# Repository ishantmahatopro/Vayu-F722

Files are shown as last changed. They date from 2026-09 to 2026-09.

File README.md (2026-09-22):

<h1 align="center">
  <br>
  Vayu F7
  <br>
</h1>

<h4 align="center">
A production-grade STM32F722 FPV flight controller built in KiCad, designed for
5-inch and 7-inch builds and documented the same way as a serious hardware
project should be.
</h4>

<div align="center">






</div>

<p align="center">
  <a href="#what-it-is">What it is</a> •
  <a href="#specifications">Specifications</a> •
  <a href="#hardware-overview">Hardware overview</a> •
  <a href="#pinout">Pinout</a> •
  <a href="#flight-controller-firmware">Firmware</a> •
  <a href="#building-one">Building one</a> •
  <a href="#license">License</a>
</p>

---

## What it is

*Vayu* (वायु) is the Sanskrit word for wind.

This is a 42 × 42 mm, four-layer FPV flight controller built around the
STM32F722 for 5-inch and 7-inch quads doing cinematic, telemetry, and general
performance work. It is designed to sit in the same class as well-known F722
boards while adding a cleaner power layout, a proper barometer, and a 10 V rail
sized for an HD VTX or analogue system.

The board is fully designed in KiCad.

## Specifications

| | |
|---|---|
| **MCU** | STM32F722RET6, Cortex-M7 @ 216 MHz, 512 KB flash, 256 KB RAM |
| **Gyro / accel** | ICM-42688-P on SPI1 |
| **Barometer** | BMP388 on I²C1 |
| **Blackbox** | W25Q128JVSIQ — 16 MB SPI NOR on its own bus |
| **OSD** | AT7456E analogue OSD, fitted |
| **Input** | 3S–6S (11.1–25.2 V), TVS clamp on the battery rail |
| **5 V BEC** | AP64350 synchronous buck, 5.00 V, 2 A |
| **10 V BEC** | AP64350 synchronous buck, 10.06 V, switchable for VTX rail |
| **3.3 V** | TLV62569 buck + LP5907-3.3 LDO for analogue rail |
| **Motor outputs** | 4 outputs with timer-backed DShot-capable design |
| **UARTs** | 6 total, with pads and connector-backed serial ports |
| **I²C** | 1, on the GPS connector |
| **Board** | 42 × 42 mm, 30.5 × 30.5 mm M3 mounting, 4 layers, 1.6 mm |
| **Stack-up** | F.Cu signal / **In1.Cu solid ground plane** / In2.Cu signal + ground pour / B.Cu signal |
| **Connectors** | ESC, GPS-I²C, RX, camera, VTX, USB-C |

### Power budget

| Rail | Source | Typical role |
|---|---|---|
| +10V | AP64350 buck | HD VTX / high-power video rail |
| +5V | AP64350 buck | main logic and peripheral rail |
| +3V3 | TLV62569 + LP5907 | MCU, IMU, barometer, logic |
| VBAT | input connector | raw battery feed for the switching rails |
| USB_VBUS | USB-C | debug / boot / low-power use |

## Pinout

The connector map is documented in the repo and kept together with the hardware
notes. The board includes the usual FPV stack connectors for:

| Connector | Purpose | Notes |
|---|---|---|
| ESC | Motor outputs and battery feed | 8-pin JST-SH style connector |
| GPS / I²C | GPS and barometer / compass bus | I²C and UART combination |
| HD VTX | Video and telemetry port | For HD VTX systems |
| RX | Serial receiver connection | Standard FPV receiver port |
| Camera | Camera connection | Analog / camera feed path |
| USB-C | DFU / flashing / debug | Board programming and serial access |

## Flight controller firmware

Because this project is a custom hardware layout, firmware is normally built from
upstream Betaflight or iNav sources rather than from a pre-generated target in a
factory build. The repository includes the custom target scaffold for both
firmware ecosystems so the board can be adapted to the normal upstream build
process.

### Betaflight

This repository now includes the custom Betaflight target definition at
[firmware/source/betaflight/config.h](firmware/source/betaflight/config.h).

1. Clone the upstream Betaflight repository.
2. Install the required GCC / toolchain dependencies.
3. Run `make configs` in the Betaflight tree.
4. Create a custom target directory, for example `src/config/configs/VAYUF7/`.
5. Copy [firmware/source/betaflight/config.h](firmware/source/betaflight/config.h)
   into that target directory.
6. Build the target with `make VAYUF7`.
7. Flash the resulting `.hex` via USB DFU or SWD.

The board mapping used in the target is aligned to the actual hardware:
- STM32F722RET6
- ICM-42688-P on SPI1
- BMP388 on I2C1
- AT7456E on SPI2
- W25Q128 on SPI3
- 4 motor outputs on timer-backed pins

### iNav

This repository also includes the custom iNav target files in
[firmware/source/inav/CMakeLists.txt](firmware/source/inav/CMakeLists.txt),
[firmware/source/inav/target.c](firmware/source/inav/target.c), and
[firmware/source/inav/target.h](firmware/source/inav/target.h).

1. Clone the upstream iNav repository.
2. Check out a supported stable release.
3. Create a target directory, for example `src/main/target/VAYUF7/`.
4. Copy the files from [firmware/source/inav](firmware/source/inav) into that
   target folder.
5. Configure the project with `cmake ..` inside the build directory.
6. Build the target with the normal iNav build command.
7. Flash the resulting `.hex` through USB or SWD.

> The hardware design is intentionally kept independent of any vendor-specific
> firmware stack so the board can be supported by upstream projects when the
> target is created.

## Building one

Current state — revision **R6**:

| Check | Result |
|---|---|
| KiCad DRC | **0 errors**, 0 unconnected pads (1 cosmetic silk warning) |
| KiCad ERC | **0 errors, 0 warnings** |
| Schematic ↔ board netlist | match, 483 pins / 105 nets, 0 mismatches |
| Electrical stress | all pass; worst capacitor 52.8 %, worst resistor 57.6 % of rating |
| HSE gain margin | 2.4× at C0 = 3 pF |
| Minimum via annular ring | 0.125 mm, every via ≥ 0.45 mm diameter |
| Datasheet cross-check | no mismatch found in the main design references |

The project is intentionally documented as a real engineering board, not just a
rendered concept. The repository includes a project status file, revision notes,
and hardware validation data so the design can be tracked from concept through
manufacturing readiness.

The main project constraints are documented openly:

- the board is input-limited on the battery connector at the real system level
- the 10 V rail is sized for VTX use but still obeys the regulator and layout
  limits
- all critical traces, regulator loops, and crystal areas are checked as part of
  the design review rather than left implicit

## Bill of material

The design uses practical, mainstream FPV parts that are suitable for a
production-style board and are chosen with sourcing and assembly in mind. The key
parts in the current hardware are:

| Category | Item | Notes |
|---|---|---|
| MCU | STM32F722RET6 | 32-bit F7 core, 216 MHz |
| IMU | ICM-42688-P | SPI-based gyro / accel |
| Barometer | BMP388 | I²C pressure sensor |
| Flash | W25Q128JVSIQ | 16 MB SPI NOR blackbox memory |
| OSD | AT7456E | Analog video overlay device |
| Regulators | AP64350 + LP5907 / TLV62569 | 5 V, 10 V, 3.3 V generation |
| Connectors | JST-SH / USB-C | Standard FPV and service interfaces |
| Board | 4-layer PCB | 42 × 42 mm, 30.5 × 30.5 mm mounting |

The repository is organized around the actual board design, not around a generic
marketing sheet. The hardware files, status records, and revision notes are the
source of truth for assembly and manufacturing decisions.

## BOM

The table below is the assembly BOM generated from the production files. Prices
are indicative USD unit prices from the currently displayed LCSC quantity tier
for the listed minimum order, checked on 2026-09-22. They exclude PCB
fabrication, assembly, shipping, tax, and tooling. `quote` means the public
product page did not expose a current price and should be checked in the JLCPCB
order quote.

| SL NO | LCSC NO | COMPONENT | PRICE IN USD |
|---:|---|---|---:|
| 1 | C29823 | C1, C2 - 4.7uF/50V, qty 2 | 0.0853 |
| 2 | C12891 | C10, C14, C15, C17, C8, C9 - 22uF/25V, qty 6 | 0.0904 |
| 3 | C1525 | C11, C5 - 100nF/16V, qty 2 | 0.0023 |
| 4 | C1531 | C12, C60 - 2.2nF, qty 2 | 0.0014 |
| 5 | C106203 | C13 - 22pF, qty 1 | 0.0023 |
| 6 | C3039694 | C16, C34 - 10uF/16V, qty 2 | 0.0699 |
| 7 | C307331 | C18, C21, C23, C24, C25, C26, C27, C30, C33, C35, C37, C38, C39, C40, C41, C42, C43, C46, C50, C51, C56, C58 - 100nF/50V, qty 22 | 0.0046 |
| 8 | C5199872 | C19, C20, C22, C49 - 1uF/50V, qty 4 | 0.0107 |
| 9 | C2885646 | C28, C29 - 4.7uF/16V, qty 2 | 0.0236 |
| 10 | C437557 | C3, C52, C53, C54, C55 - 4.7uF/50V, qty 5 | 0.1152 |
| 11 | C107004 | C31, C32 - 15pF, qty 2 | 0.0013 |
| 12 | C415535 | C36 - 2.2uF/16V, qty 1 | 0.0412 |
| 13 | C14663 | C4 - 100nF/50V, qty 1 | 0.0052 |
| 14 | C45783 | C47, C48 - 22uF/16V, qty 2 | 0.1037 |
| 15 | C189470 | C59 - 6.8pF, qty 1 | 0.0016 |
| 16 | C107024 | C6 - 1.8nF, qty 1 | 0.0021 |
| 17 | C107002 | C7 - 27pF, qty 1 | 0.0015 |
| 18 | C908777 | D1 - SMAJ33A, qty 1 | 0.0167 |
| 19 | C64885 | D4 - B5819W, qty 1 | 0.0091 |
| 20 | C2286 | D5 - RED 3V3, qty 1 | 0.0035 |
| 21 | C965804 | D6 - GREEN 5V, qty 1 | 0.0031 |
| 22 | C965802 | D7 - YELLOW VBAT, qty 1 | 0.0038 |
| 23 | C965807 | D8 - BLUE STATUS, qty 1 | 0.0027 |
| 24 | C1017 | FB1 - 600R@100MHz 2A, qty 1 | quote |
| 25 | C160407 | J1 - ESC 8P, qty 1 | 0.1840 |
| 26 | C53055322 | J2 - HD VTX 6P, qty 1 | 0.0349 |
| 27 | C160404 | J3 - RX 4P, qty 1 | 0.1245 |
| 28 | C53055322 | J4 - GPS/I2C 6P, qty 1 | 0.0349 |
| 29 | C160404 | J5 - CAM 4P, qty 1 | 0.1245 |
| 30 | C160404 | J6 - VTX 4P, qty 1 | 0.1245 |
| 31 | C165948 | J8 - USB-C 16P, qty 1 | 0.0971 |
| 32 | C167221 | L1 - 6.8uH FXL0630-6R8-M, qty 1 | 0.0827 |
| 33 | C189932 | L2 - 10uH SRP5030T-100M, qty 1 | 0.6640 |
| 34 | C50543 | L3 - 2.2uH SWPA4018S2R2MT, qty 1 | quote |
| 35 | C8545 | Q1 - 2N7002, qty 1 | 0.0106 |
| 36 | C20917 | Q2 - AO3400A, qty 1 | 0.0482 |
| 37 | C159047 | R1, R7 - 294k, qty 2 | 0.0004 |
| 38 | C25748 | R10 - 118k, qty 1 | 0.0013 |
| 39 | C5153958 | R11, R5 - 10.2k, qty 2 | 0.0010 |
| 40 | C2998091 | R12 - 31.6k, qty 1 | 0.0014 |
| 41 | C25744 | R13, R14, R20, R28, R34, R35, R36, R37, R38, R50 - 10k, qty 10 | 0.0017 |
| 42 | C25905 | R16, R17 - 5.1k, qty 2 | 0.0012 |
| 43 | C25879 | R18, R19, R25, R26, R39 - 2.2k, qty 5 | 0.0026 |
| 44 | C2960799 | R2, R8 - 57.6k, qty 2 | 0.0012 |
| 45 | C2909384 | R21, R22 - 75R, qty 2 | 0.0013 |
| 46 | C25804 | R23 - 10k, qty 1 | 0.0012 |
| 47 | C11702 | R24, R30, R33, R40, R41 - 1k, qty 5 | 0.0012 |
| 48 | C25741 | R27, R49 - 100k, qty 2 | 0.0013 |
| 49 | C22369194 | R29 - 100R, qty 1 | quote |
| 50 | C2909325 | R3 - 180k, qty 1 | 0.0012 |
| 51 | C25867 | R31 - 1.5k, qty 1 | 0.0013 |
| 52 | C22809 | R32 - 15k, qty 1 | 0.0014 |
| 53 | C53398 | R4 - 53.6k, qty 1 | 0.0008 |
| 54 | C2906868 | R42, R43, R44, R45, R47 - 33R, qty 5 | 0.0012 |
| 55 | C3013172 | R48 - 453k, qty 1 | 0.0013 |
| 56 | C2998160 | R6 - 25.5k, qty 1 | 0.0013 |
| 57 | C2909311 | R9 - 110k, qty 1 | 0.0009 |
| 58 | C231329 | SW1 - BOOT, qty 1 | 0.1025 |
| 59 | C2071691 | U1, U2 - AP64350SP-13, qty 2 | 1.1554 |
| 60 | C82351 | U10 - AT7456E, qty 1 | 1.7093 |
| 61 | C141836 | U3 - TLV62569DBVR, qty 1 | 0.0441 |
| 62 | C80670 | U4 - LP5907MFX-3.3, qty 1 | 0.1260 |
| 63 | C118207 | U5 - STM32F722RET6, qty 1 | 6.9322 |
| 64 | C2687116 | U6 - USBLC6-2SC6, qty 1 | 0.0221 |
| 65 | C1850418 | U7 - ICM-42688-P, qty 1 | 15.6022 |
| 66 | C779278 | U8 - BMP388, qty 1 | 3.6120 |
| 67 | C97521 | U9 - W25Q128JVSIQ, qty 1 | 1.6422 |
| 68 | C2682775 | X1 - 8MHz X32258MOB4SI 12pF, qty 1 | 0.0937 |
| 69 | C9008 | X2 - 27MHz X322527MSB4SI, qty 1 | 0.0489 |
| 70 | | PCB, qty 5 | 27.54 |
| 71 | | PCBA, qty 2 | 130

## Board renders

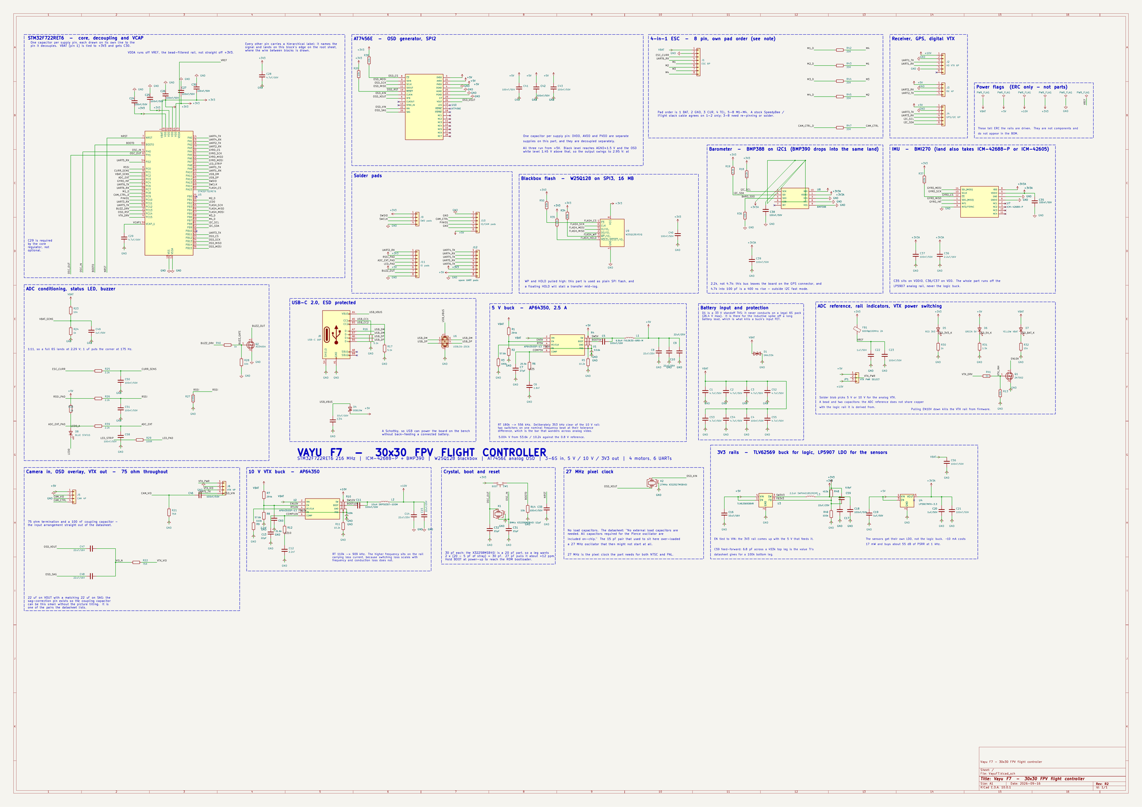
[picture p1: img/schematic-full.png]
schematic


### - If its hard to zoom please check out /img folder to see each part of the schematic much more clearly, I tried using .pdf to .img but unfortunately u can't see the text on zooming in... hence I have taken SS of each component.

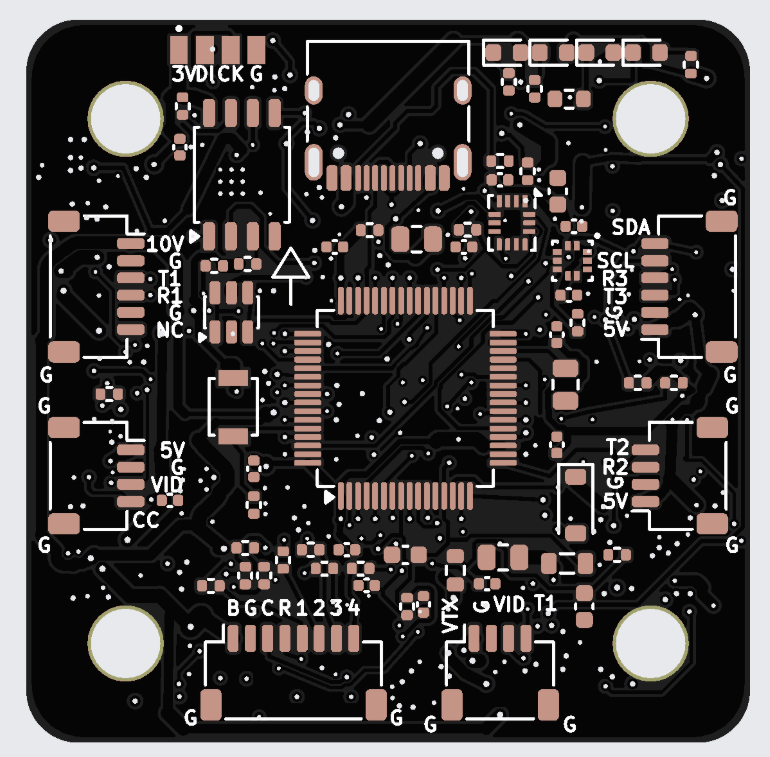
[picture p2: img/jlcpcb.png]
JLCPCB


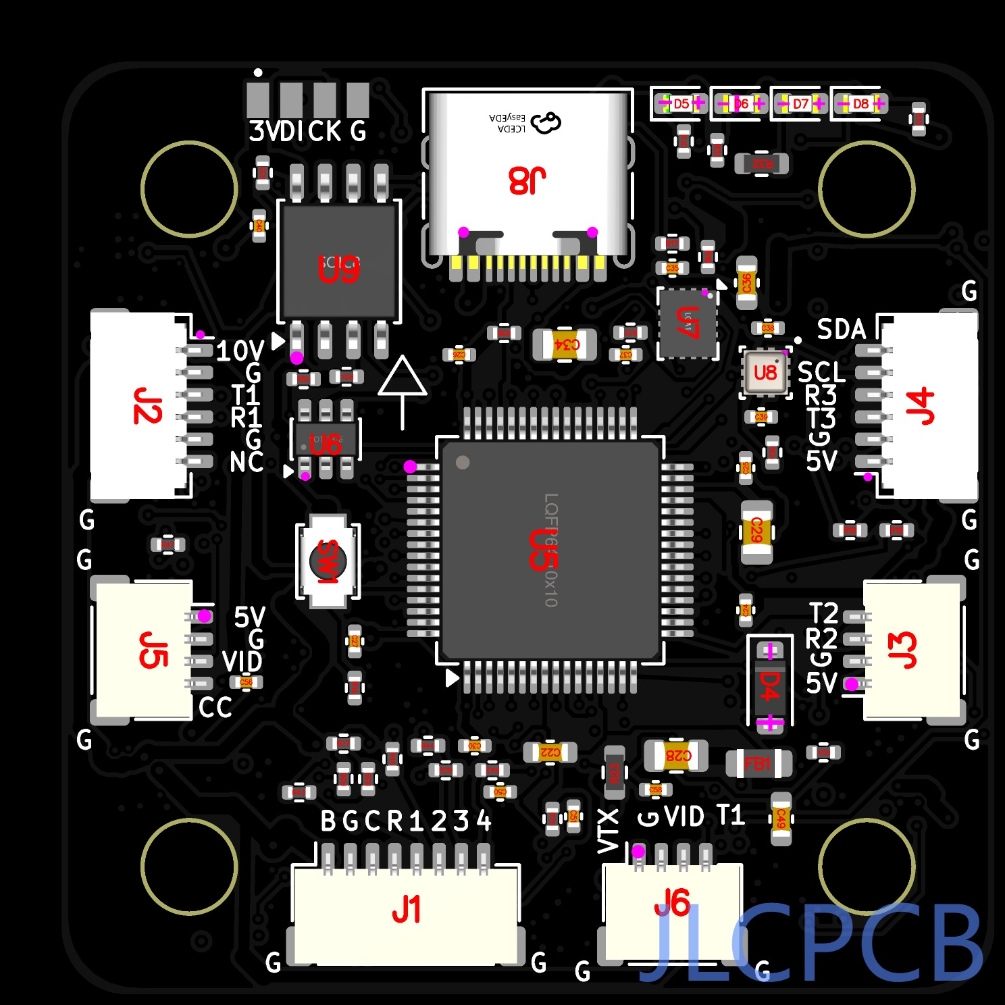
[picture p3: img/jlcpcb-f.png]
Front


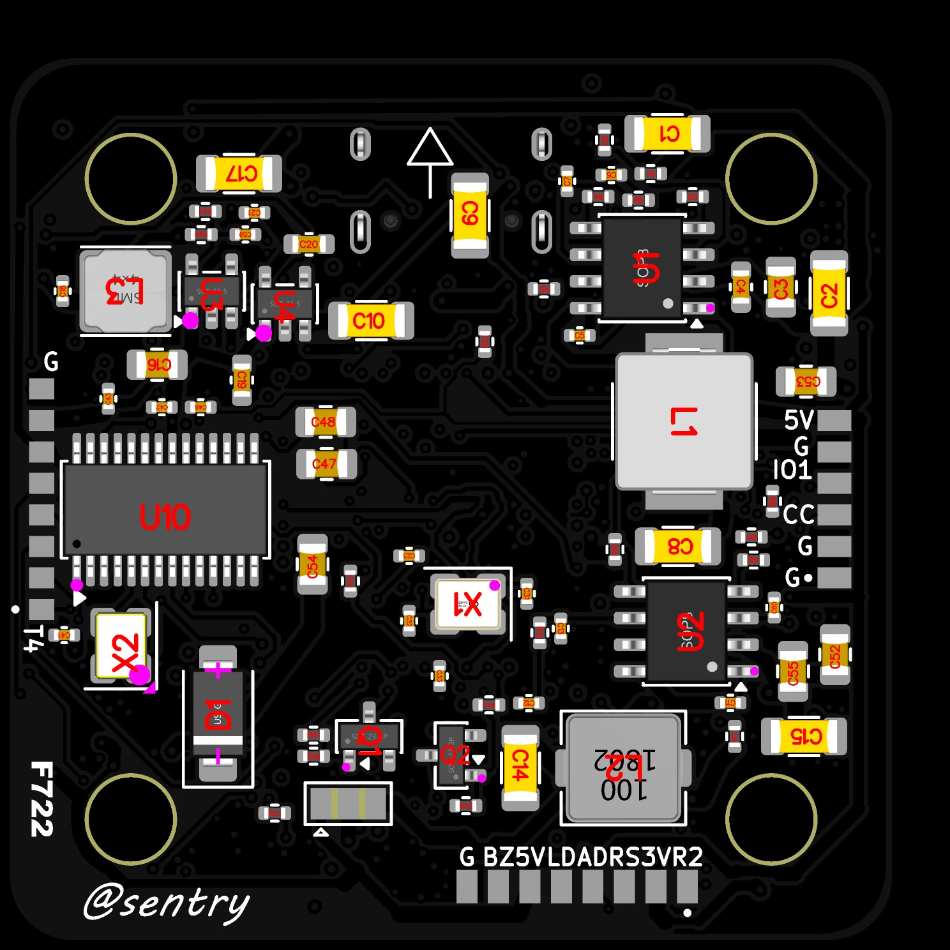
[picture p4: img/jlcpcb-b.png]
Back


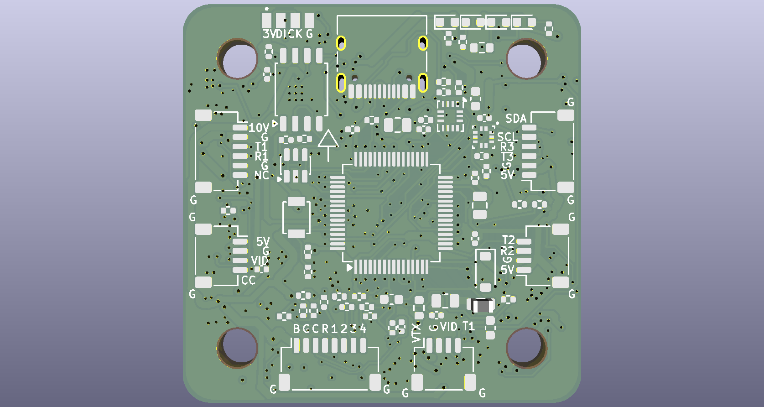
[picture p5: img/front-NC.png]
Vayu F7 front render without components


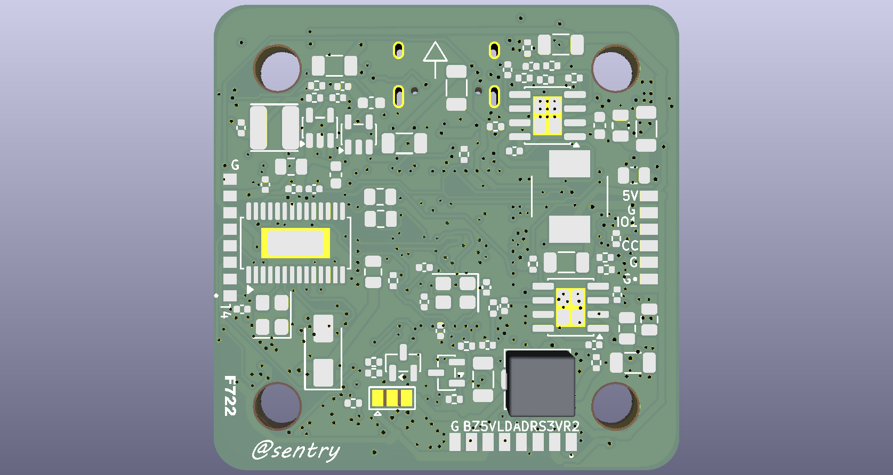
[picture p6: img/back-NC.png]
Vayu F7 back render without components


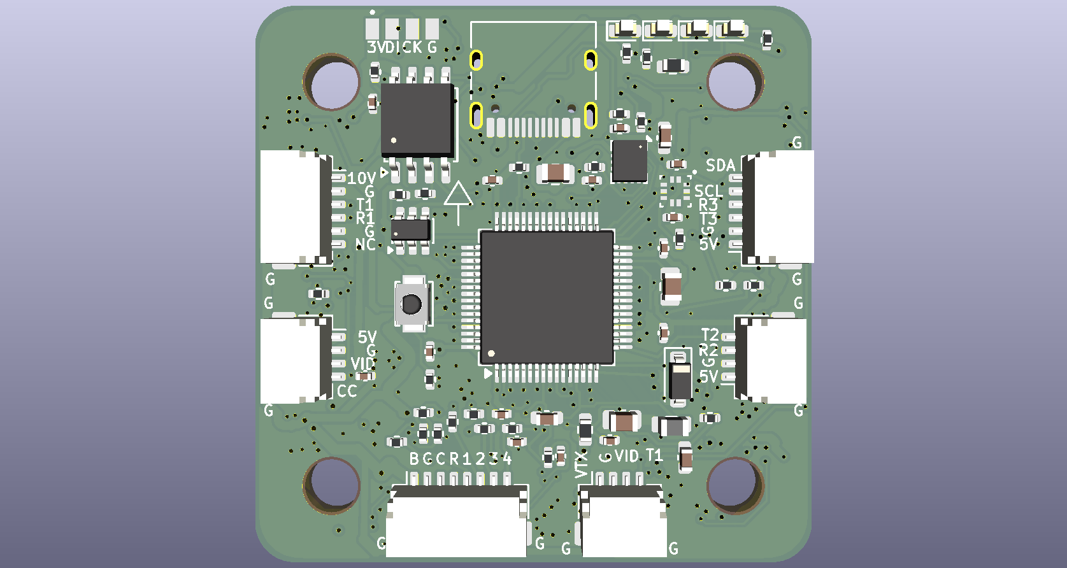
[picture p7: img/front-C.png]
Vayu F7 front render with components


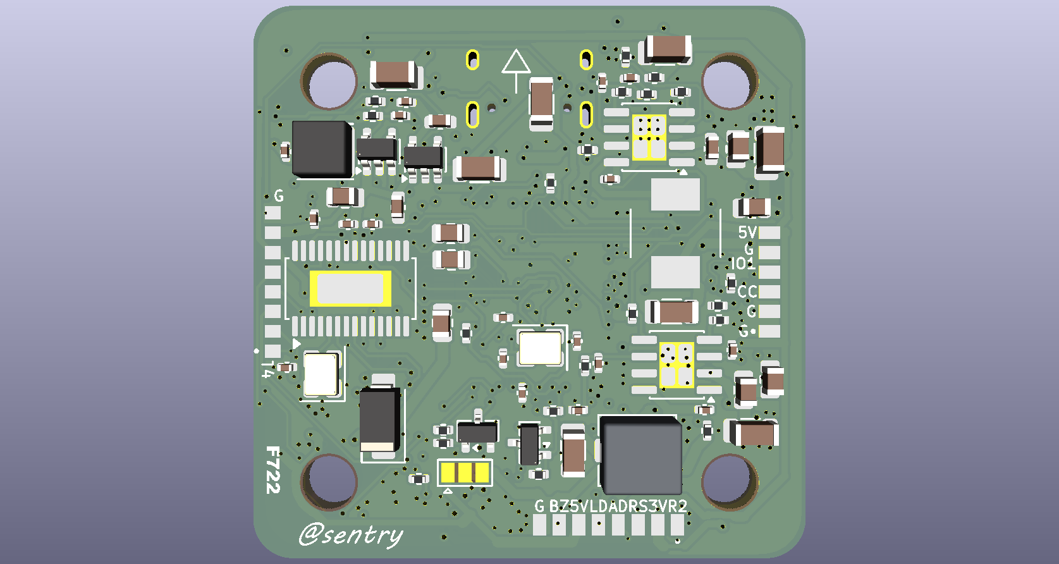
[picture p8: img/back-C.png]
Vayu F7 back render with components


## Credits

- [KiCad](https://www.kicad.org/)
- [INAV](https://github.com/iNavFlight/inav)
- [Betaflight](https://github.com/betaflight/betaflight)
- [JLCPCB](https://jlcpcb.com/) and [LCSC](https://www.lcsc.com/)
- [Hack Club Blueprint](https://blueprint.hackclub.com/)
- The original open hardware and design process references that inspired this
  board-level documentation approach

## AI usage
This project was designed and built with the help of AI ChatGPT 5.6 precisely... AI was used to extract key important design rules for different componets pulling it off their 200pages chinglish docs ( chinese + english ). Help in creating a netlist, chosing components and drawing the schematic.
Also AI was used in writing the firmware...

> As mentioned in the resource docs, no AI was used to write slopped Journal or REAMDE.

## License

MIT

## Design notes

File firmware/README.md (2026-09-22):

# Vayu F7 firmware targets

This directory contains the custom upstream target scaffolding for the Vayu F7 hardware.

The board is designed around an STM32F722RET6, a 3-axis gyro / accel sensor, a BMP388 barometer, a W25Q128 blackbox flash chip, and a standard FPV serial / video stack. The target files here are intentionally kept generic so they can be dropped into the upstream build trees for Betaflight and iNav without depending on a vendor-specific firmware package.

## Included targets

- `source/betaflight/config.h` — Betaflight target definition for a custom `VAYUF7` target.
- `source/inav/CMakeLists.txt` — iNav target registration
- `source/inav/target.c` — timer and output mapping
- `source/inav/target.h` — board identifier and peripheral map

## Hardware assumptions

The scaffold is aligned to the live Vayu F7 schematic and current design notes:

- MCU: STM32F722RET6
- Gyro / accel: ICM-42688-P on SPI1
- Barometer: BMP388 on I2C1
- OSD: AT7456E on SPI2
- Blackbox flash: W25Q128 on SPI3
- Motor outputs: 4 timer-backed outputs on TIM1/TIM2-style mappings
- UARTs: standard serial ports for RX / GPS / telemetry / VTX / debug

## Building upstream targets

### Betaflight

1. Clone the upstream Betaflight repository.
2. Install the required toolchain.
3. Copy `source/betaflight/config.h` into the relevant custom target directory in the Betaflight tree.
4. Build with the normal target generation flow for the board.
5. Flash the resulting firmware through USB DFU or SWD.

### iNav

1. Clone the upstream iNav repository.
2. Add the files in `source/inav/` into the matching target subdirectory.
3. Regenerate the target config and build via the normal iNav CMake flow.
4. Flash the compiled firmware using the standard method for the project.

## Notes

These files are a recovery scaffold for upstream firmware integration. They are not a complete factory firmware build, and they should be used as the starting point for final target validation inside the proper Betaflight / iNav upstream repos.

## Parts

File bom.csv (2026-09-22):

Designator | Footprint | Quantity | Value | LCSC Part #
C1, C2 | 1206 | 2 | 4.7uF/50V | C29823
C10, C14, C15, C17, C8, C9 | 1206 | 6 | 22uF/25V | C12891
C11, C5 | 0402 | 2 | 100nF/16V | C1525
C12, C60 | 0402 | 2 | 2.2nF | C1531
C13 | 0402 | 1 | 22pF | C106203
C16, C34 | 0805 | 2 | 10uF/16V | C3039694
C18, C21, C23, C24, C25, C26, C27, C30, C33, C35, C37, C38, C39, C40, C41, C42, C43, C46, C50, C51, C56, C58 | 0402 | 22 | 100nF/50V | C307331
C19, C20, C22, C49 | 0603 | 4 | 1uF/50V | C5199872
C28, C29 | 0805 | 2 | 4.7uF/16V | C2885646
C3, C52, C53, C54, C55 | 0805 | 5 | 4.7uF/50V | C437557
C31, C32 | 0402 | 2 | 15pF | C107004
C36 | 0603 | 1 | 2.2uF/16V | C415535
C4 | 0603 | 1 | 100nF/50V | C14663
C47, C48 | 0805 | 2 | 22uF/16V | C45783
C59 | 0402 | 1 | 6.8pF | C189470
C6 | 0402 | 1 | 1.8nF | C107024
C7 | 0402 | 1 | 27pF | C107002
D1 | D_SMA | 1 | SMAJ33A | C908777
D4 | D_SOD-123 | 1 | B5819W | C64885
D5 | 0603 | 1 | RED 3V3 | C2286
D6 | 0603 | 1 | GREEN 5V | C965804
D7 | 0603 | 1 | YELLOW VBAT | C965802
D8 | 0603 | 1 | BLUE STATUS | C965807
FB1 | 0805 | 1 | 600R@100MHz 2A | C1017
J1 | JST_SH_SM08B-SRSS-TB_1x08-1MP_P1.00mm_Horizontal | 1 | ESC 8P | C160407
J2 | JST_SH_SM06B-SRSS-TB_1x06-1MP_P1.00mm_Horizontal | 1 | HD VTX 6P | C53055322
J3 | JST_SH_SM04B-SRSS-TB_1x04-1MP_P1.00mm_Horizontal | 1 | RX 4P | C160404
J4 | JST_SH_SM06B-SRSS-TB_1x06-1MP_P1.00mm_Horizontal | 1 | GPS/I2C 6P | C53055322
J5 | JST_SH_SM04B-SRSS-TB_1x04-1MP_P1.00mm_Horizontal | 1 | CAM 4P | C160404
J6 | JST_SH_SM04B-SRSS-TB_1x04-1MP_P1.00mm_Horizontal | 1 | VTX 4P | C160404
J8 | USB_C_Receptacle_HRO_TYPE-C-31-M-12 | 1 | USB-C 16P | C165948
L1 | L_cjiang_FXL0630 | 1 | 6.8uH FXL0630-6R8-M | C167221
L2 | L_Bourns_SRP5030T | 1 | 10uH SRP5030T-100M | C189932
L3 | L_Sunlord_SWPA4018S | 1 | 2.2uH SWPA4018S2R2MT | C50543
Q1 | SOT-23 | 1 | 2N7002 | C8545
Q2 | SOT-23 | 1 | AO3400A | C20917
R1, R7 | 0402 | 2 | 294k | C159047
R10 | 0402 | 1 | 118k | C25748
R11, R5 | 0402 | 2 | 10.2k | C5153958
R12 | 0402 | 1 | 31.6k | C2998091
R13, R14, R20, R28, R34, R35, R36, R37, R38, R50 | 0402 | 10 | 10k | C25744
R16, R17 | 0402 | 2 | 5.1k | C25905
R18, R19, R25, R26, R39 | 0402 | 5 | 2.2k | C25879
R2, R8 | 0402 | 2 | 57.6k | C2960799
R21, R22 | 0402 | 2 | 75R | C2909384
R23 | 0603 | 1 | 10k | C25804
R24, R30, R33, R40, R41 | 0402 | 5 | 1k | C11702
R27, R49 | 0402 | 2 | 100k | C25741
R29 | 0402 | 1 | 100R | C22369194
R3 | 0402 | 1 | 180k | C2909325
R31 | 0402 | 1 | 1.5k | C25867
R32 | 0603 | 1 | 15k | C22809
R4 | 0402 | 1 | 53.6k | C53398
R42, R43, R44, R45, R47 | 0402 | 5 | 33R | C2906868
R48 | 0402 | 1 | 453k | C3013172
R6 | 0402 | 1 | 25.5k | C2998160
R9 | 0402 | 1 | 110k | C2909311
SW1 | SW_SPST_B3U-1000P | 1 | BOOT | C231329
U1, U2 | SOIC-8-1EP_3.9x4.9mm_P1.27mm_EP2.62x3.51mm | 2 | AP64350SP-13 | C2071691
U10 | HTSSOP-28-1EP_4.4x9.7mm_P0.65mm_EP2.75x6.2mm | 1 | AT7456E | C82351
U3 | SOT-23-5 | 1 | TLV62569DBVR | C141836
U4 | SOT-23-5 | 1 | LP5907MFX-3.3 | C80670
U5 | LQFP-64_10x10mm_P0.5mm | 1 | STM32F722RET6 | C118207
U6 | SOT-23-6 | 1 | USBLC6-2SC6 | C2687116
U7 | Bosch_LGA-14_3x2.5mm_P0.5mm | 1 | ICM-42688-P | C1850418
U8 | Bosch_LGA-10_2x2mm_BMP388_BMP390 | 1 | BMP388 | C779278
U9 | SOIC-8_5.3x5.3mm_P1.27mm | 1 | W25Q128JVSIQ | C97521
X1 | Crystal_SMD_3225-4Pin_3.2x2.5mm | 1 | 8MHz X32258MOB4SI 12pF | C2682775
X2 | Crystal_SMD_3225-4Pin_3.2x2.5mm | 1 | 27MHz X322527MSB4SI | C9008

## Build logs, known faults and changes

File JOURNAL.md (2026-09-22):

---
title: "Vayu F7 Flight Controller"
author: "Ishant Mahato"
description: "A 42x42mm 4-layer STM32F722 FPV flight controller for 5in and 7in cinematic and telemetry quads, built from a blank KiCad project. Six revisions from the first comparison table to fabrication-ready files."
created_at: "2026-09-02"
---

# September 02: what this thing actually has to be

Starting a new project. A 4-layer STM32F722 flight controller for 5" and 7"
cinematic and telemetry quads, carrying a DJI Osmo Pocket 4. Working name Vayu,
which is the Sanskrit word for wind.

I didn't draw anything today. The brief I set myself was "equal to or better than
a SpeedyBee F722 V4 and an iFlight BLITZ F722", and "better" is meaningless until
you write down what you are beating, so I pulled up both boards and made a table.

| | SpeedyBee F722 V4 | iFlight BLITZ F722 | what I want |
| --- | --- | --- | --- |
| MCU | STM32F722 216 MHz | STM32F722 216 MHz  | same |
| Gyro | ICM-42688-P / BMI270 | ICM-42688-P | same class  |
| Baro | SPL06 / BMP280 | BMP280 | better |
| Blackbox | 16 MB flash | 16 MB flash | same |
| BEC | 5 V 2.5 A + 9 V 2 A  | 5 V 2 A + 10 V 2 A | same |
| UARTs | 6 | 6 | 6 |
| Input | 3-6S | 3-6S | 3-6S |
| Mounting | 30.5 x 30.5 | 30.5 x 30.5 | 30.5 x 30.5 |

Two things came out of that immediately. First, 30.5 x 30.5 is a _mounting_
pattern, not a board size, so the board can be bigger than the hole spacing.
Second, both of those boards advertise six UARTs and I assumed that was a
marketing number until I checked, which is tomorrow's problem.

I also decided what I am _not_ building. No SD card - flash is smaller, faster to
write and doesn't rattle loose. No second IMU. No CAN. The mission is cinematic
HD plus telemetry, not racing, and every one of those would cost me board area I
don't have.

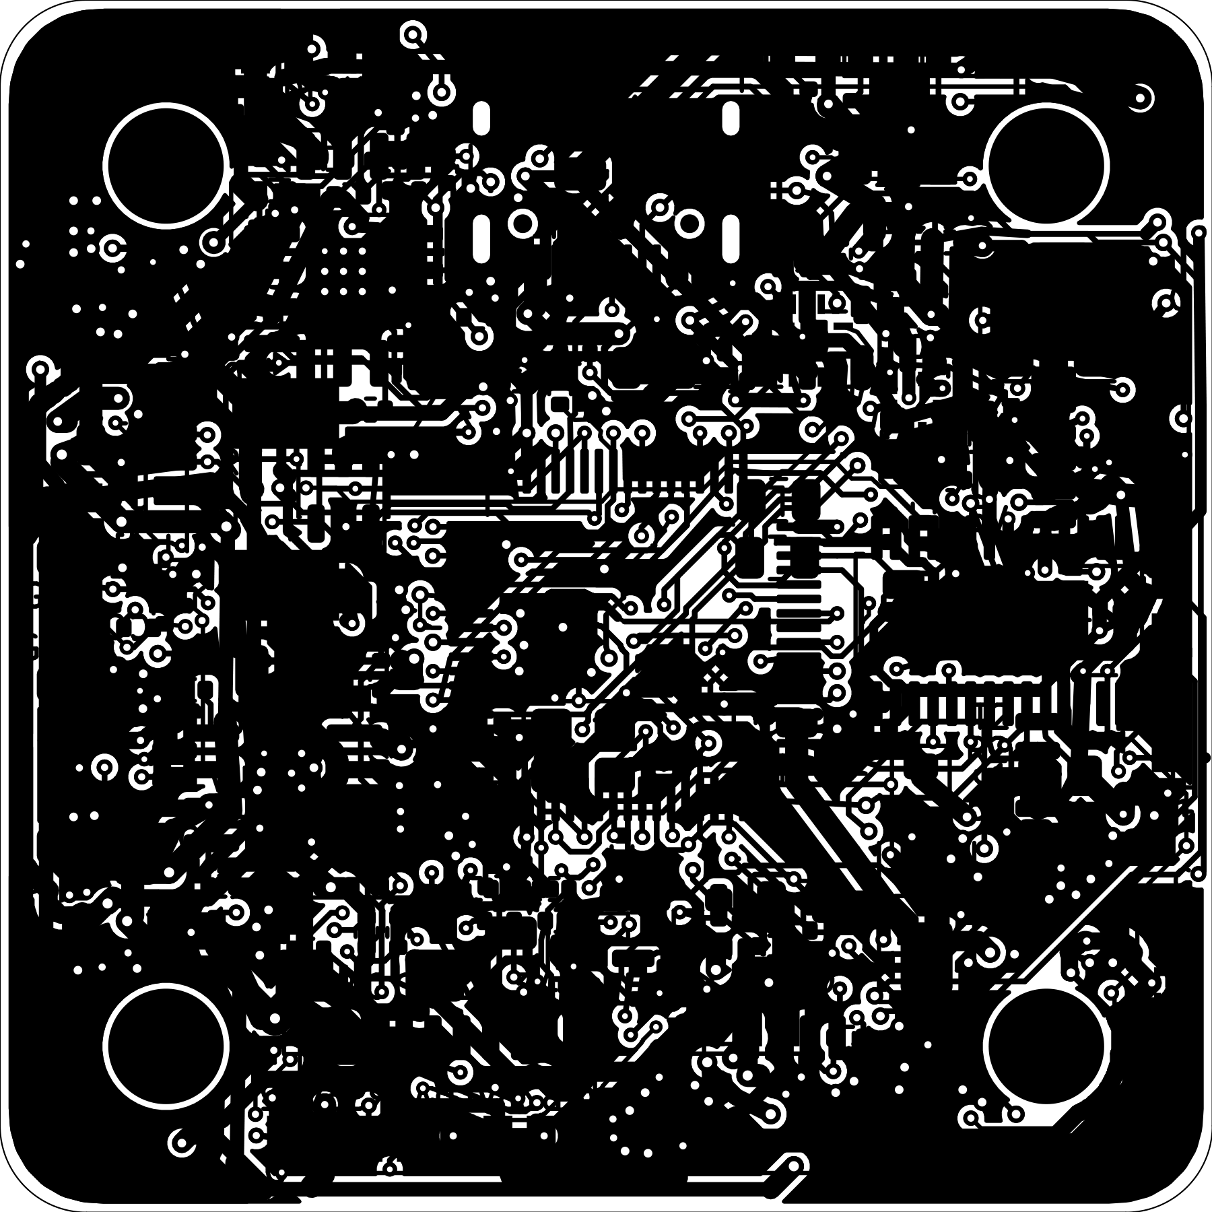
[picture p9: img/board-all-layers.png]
the board this turned into


**Total time spent: 2.4 hours**

# September 03: picking the MCU

Today was reading the STM32F722 datasheet and deciding whether it is actually the
right chip, rather than the one I had already decided on.

I looked at the F405 and the H743 as well. The F405 is barely an upgrade on what
is already common and has no headroom for an 8k PID loop. The H743 is lovely and
I cannot afford it, and when I was looking it was out of stock everywhere I could
buy from anyway. F722 it is: 216 MHz, 512 kB flash, and mature in both Betaflight
and INAV so I am not the person debugging the target.

Then I found the thing I had assumed was marketing. **The F722 in the LQFP-64
package only has six usable UARTs.** The datasheet lists eight, but UART7 and
UART8 live on port E and port F, and those ports are simply not bonded out on the
64-pin package. Every F722 board on the market says six for exactly this reason.

That matters because I wanted "two spare UARTs for future proofing" and had been
treating that as extra. It is not extra. It comes out of the six. So the plan
becomes: four UARTs committed (receiver, VTX, GPS, ESC telemetry), two spare, and
the spare ones get brought out to solder pads rather than connectors so they cost
me almost no area.

Decoupling rule I set myself while I was in there, and kept for the whole build:
one capacitor per supply pin, each drawn on its own line to the pin it decouples.
It makes the schematic longer and the layout obvious.

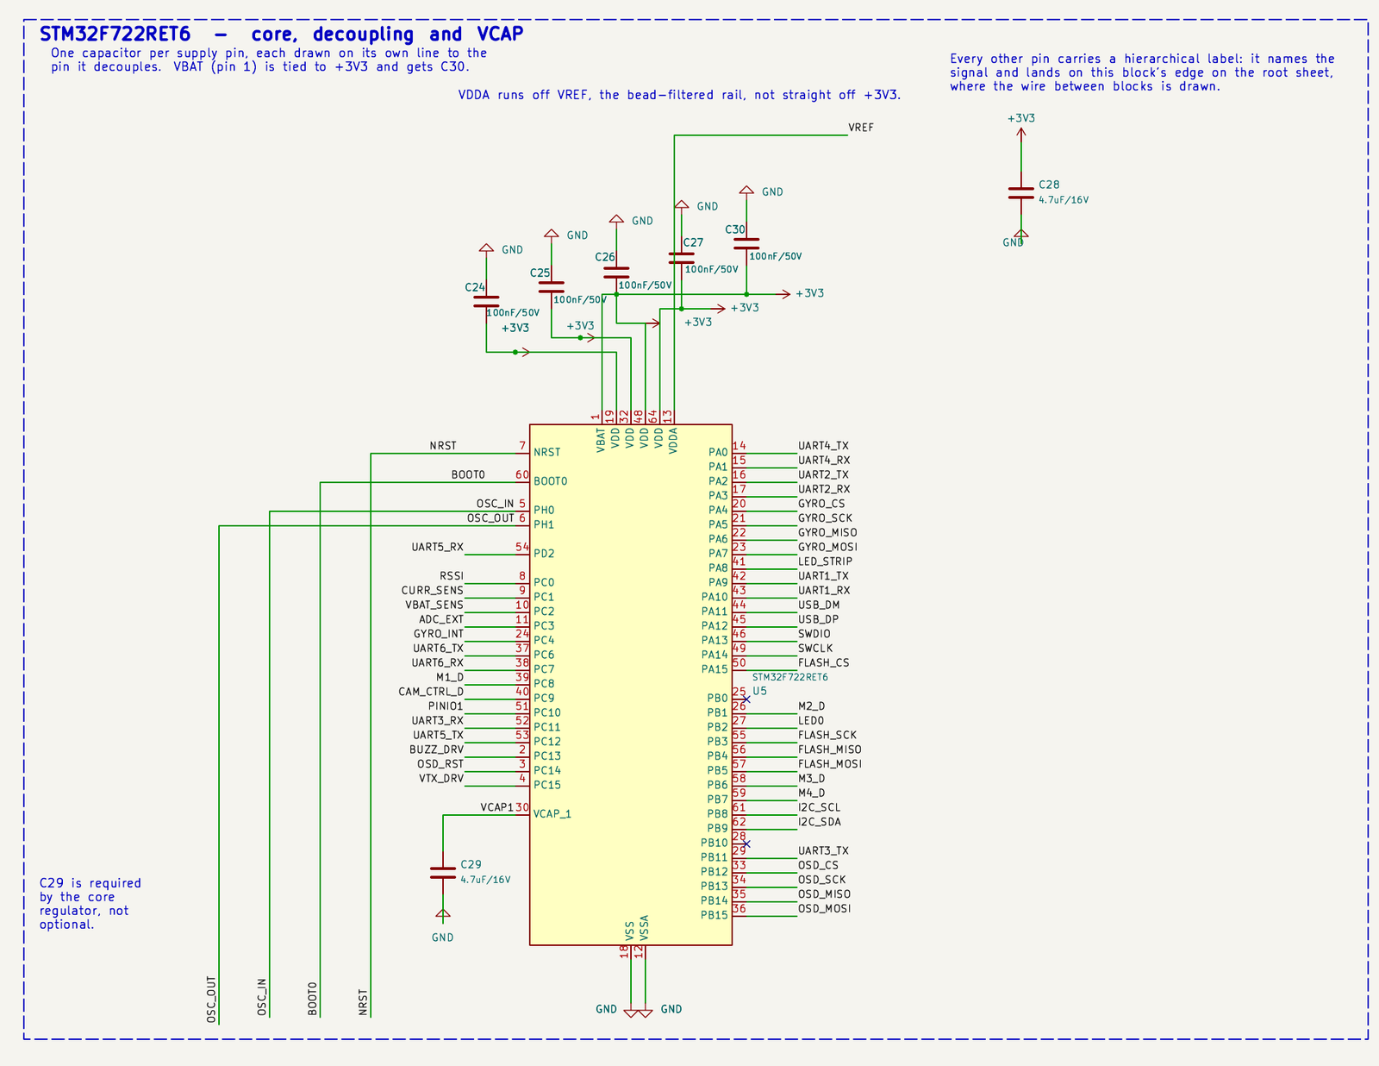
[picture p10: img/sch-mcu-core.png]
the MCU block, with the decoupling drawn one cap per supply pin


**Total time spent: 2.8 hours**

# September 04: the gyro, and one footprint for three parts

Gyro day. This is the part that decides how the quad flies, and it is also the
part I am least able to buy reliably, which turns out to be the whole story.

The shortlist was ICM-42688-P, BMI270 and ICM-42605. The 42688 is the best of the
three - lower noise, 32 kHz output, and it is what the BLITZ uses. The BMI270 is
what you fall back to when the 42688 is unobtainable, which in India it very
often is. The 42605 is the cheap one.

Rather than pick one and hope, I checked the three datasheets against each other
pin by pin and found they share a 14-pin 3 x 2.5 mm LGA footprint with compatible
pinouts for everything I need: SPI, interrupt, both supplies. **So I drew one
footprint that takes any of the three** and wrote the differences into the
schematic as text - mainly that pin 9 is INT2/FSYNC/CLKIN on the TDK parts and
has to be tied to GND when FSYNC is unused, which is straight out of TDK's
datasheet.

That felt like the cleverest thing I had done all week. It is worth saying now
that a week later I worked out it was clever about a problem I had invented for
myself, and the entry for the 9th explains why.

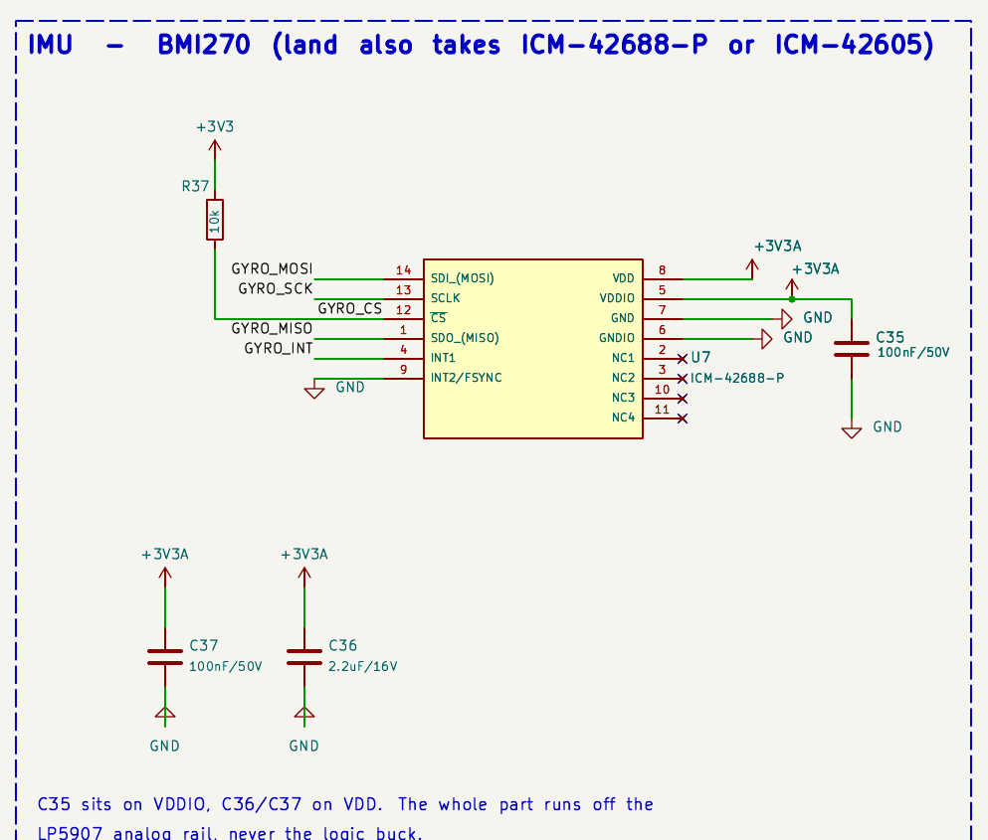
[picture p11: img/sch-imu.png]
the gyro block - one footprint, three possible parts


**Total time spent: 2.6 hours**

# September 05: baro, OSD and blackbox

Filling in the rest of the sensor and peripheral picks.

**Barometer.** Both reference boards use a BMP280 or an SPL06. I want better,
because altitude hold and GPS rescue accuracy live and die on baro noise. The
BMP390 is the obvious upgrade. Noted it and moved on, and this comes back to bite
me when I actually try to buy one.

**OSD.** AT7456E, which is a clone of the MAX7456. The alternative is MSP
DisplayPort drawn by the goggles, which costs zero hardware, but that only works
on digital systems and I want the board to be useful on analog too. So the analog
OSD goes on, with its own 27 MHz pixel clock and the video path around it.

**Blackbox.** W25Q128JVSIQ, 16 MB, SOIC-8, on its own SPI bus. 16 MB is about
twenty minutes of useful logging at the rates I care about. I looked at the
smaller WSON packages to save area and decided the SOIC-8 leads are worth the
space, because I might have to hand-solder one.

Three SPI buses, then: gyro on its own, OSD on its own, flash on its own. The
gyro absolutely cannot share a bus with anything - the timing of that data _is_
the flight performance.

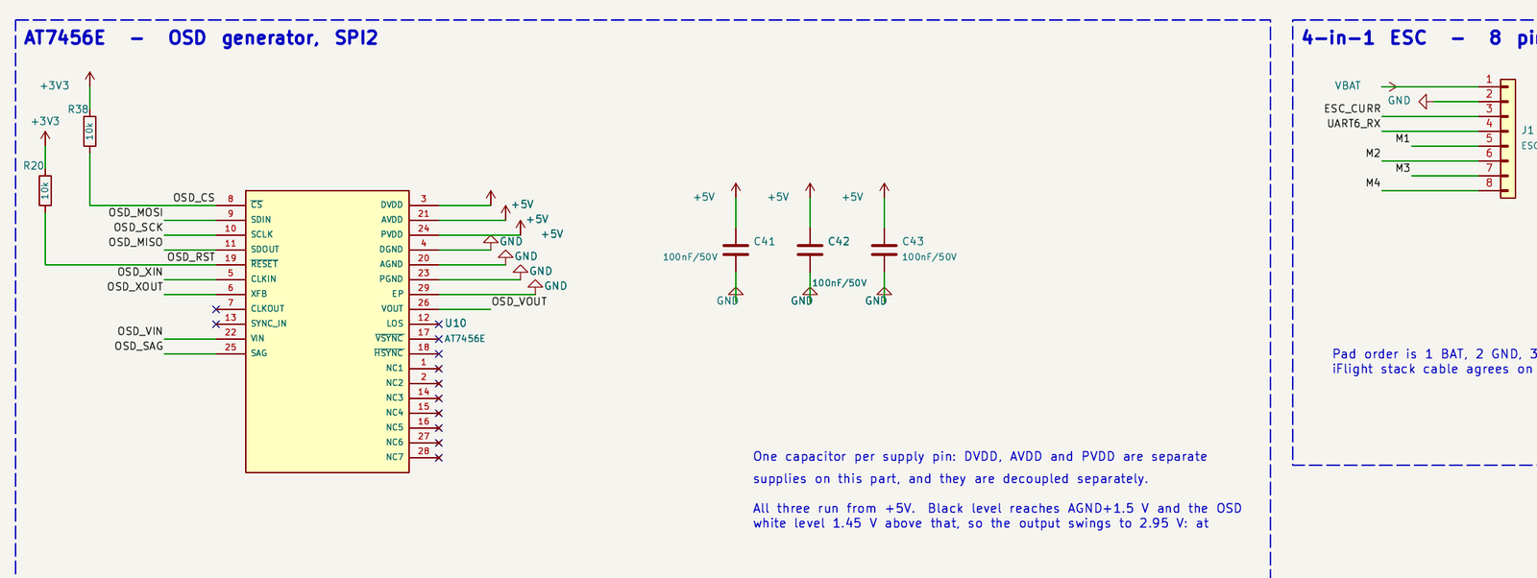
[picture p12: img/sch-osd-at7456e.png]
the AT7456E analog OSD


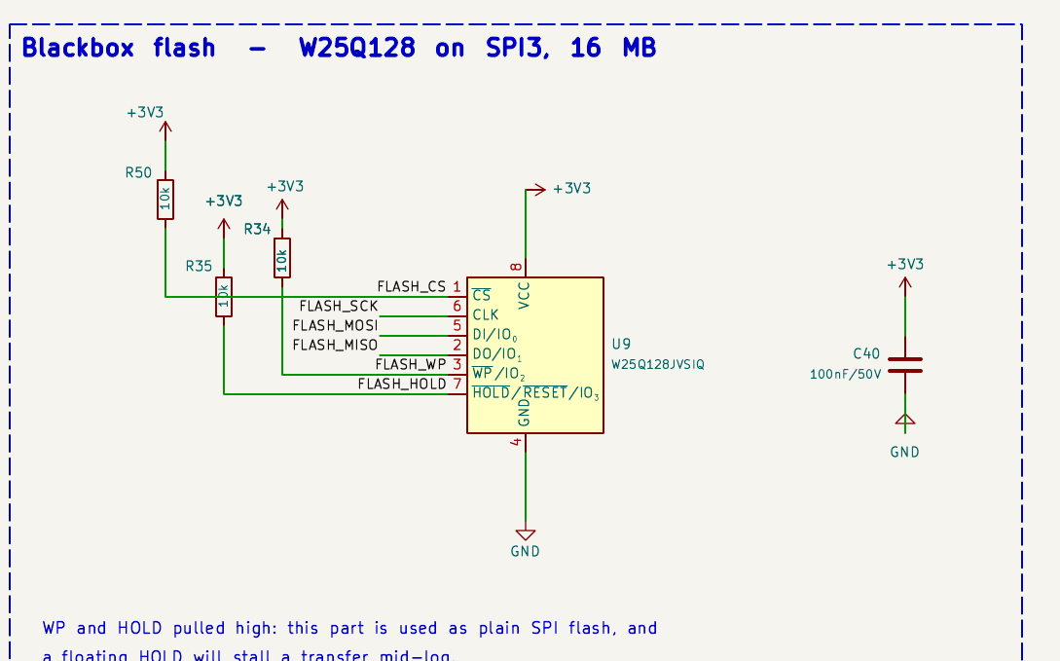
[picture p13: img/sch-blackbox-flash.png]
the blackbox flash on its own SPI bus


**Total time spent: 2.1 hours**

# September 06: two suppliers and a lot of dead ends

The hard constraint I set myself: every part from lioncircuits.com or robu.in.
Nothing else. No LCSC, no AliExpress. The idea was that if I am in India, buying
in India avoids the entire import mess.

I have never had sourcing drive a design this hard before. I wrote a small
scraper against the LionCircuits part pages - they ship a `__NEXT_DATA__` JSON
blob with stock, lead time and the full price-break table - and started checking
candidates _before_ drawing them.

What I found, in the order it hurt:

**The OSD isn't in either catalogue.** LionCircuits lists MAX7456EUI+ with no
offer. So the analog OSD has to go on the board as a do-not-populate option: the
footprint, the crystal, the video path and the decoupling all there, shipping
unpopulated, with a part number in the docs for whoever wants it. That is a
genuinely bad outcome for a feature I wanted.

**The 3.3 V regulator I picked is out of stock.** TLV1117LV33, gone. Went looking
for SOT-223 alternatives and landed on AZ1117CH-3.3TRG1 at 8.48 rupees with 10k
in stock. SOT-223 matters: the same part in SOT-23-5 would dissipate
(5 - 3.3) x 0.4 = 0.68 W in a package with about 190 C/W, which is a 129 degree
rise. SOT-223 is about 60 C/W. Package choice _is_ the thermal design.

**The USB-C connector** KiCad has a footprint for isn't there either. GCT
USB4105-GF-A is, with 138,999 in stock, and KiCad ships the official footprint
drawn from GCT's own drawing. It has through-hole shield legs, which I care about
more than the price - the number one way a flight controller dies is somebody
yanking the USB cable sideways and tearing an SMD connector off the board.

About 120 part numbers queried today. Not one line of schematic drawn. Worth it.

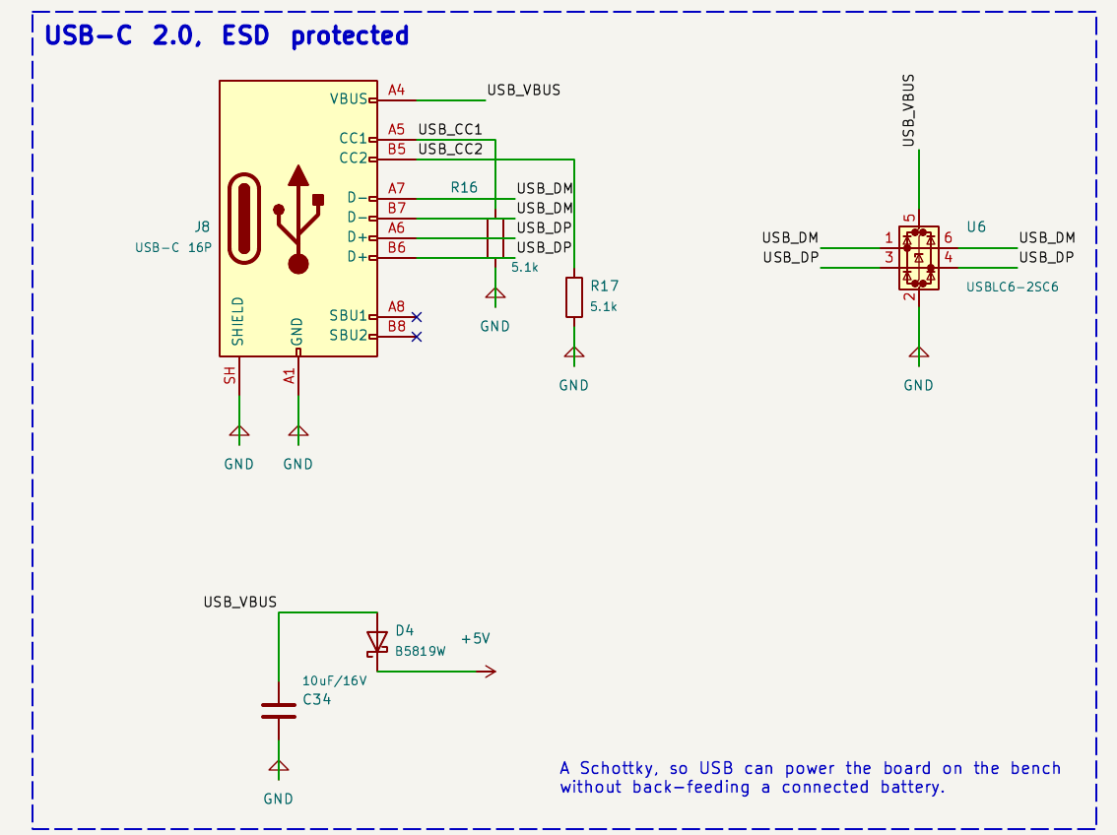
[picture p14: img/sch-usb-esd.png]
USB-C with the ESD part and the through-hole shield legs


**Total time spent: 3.4 hours**

# September 07: power maths before I draw anything

Two buck converters. Both TPS54540 at this point - 42 V in, 5 A, in stock at 374
rupees, which matters because at 6S I am feeding them 25.2 V and most cheap bucks
top out below that.

Did the arithmetic before drawing a single symbol, because a buck you size by
guessing is a buck that runs hot and you find out about it in the air.

**5 V rail.** Loads: MCU and sensors through the 3.3 V regulator, receiver
100 mA, GPS 100 mA, camera 150 mA, OSD 40 mA, LED strip up to 500 mA, buzzer
30 mA. Call it 1.4 A worst case, and that is genuinely worst case, because nobody
runs a full LED strip and a GPS and a camera flat out at the same time.

**10 V rail for the VTX.** An HD air unit peaks around 1.2 A, so about 11 W. I
sized the rail at 2 A for headroom.

Then the inductors. Ripple current is Vout x (1 - Vout/Vin) / (L x fsw), and at
6S in with a 6.8 uH inductor the 5 V rail comes out around 1 A peak-to-peak,
which is fine on a 3.5 A part. I picked inductors on **saturation current** rather
than inductance alone, which I think is the mistake most people make - a 6.8 uH
part that saturates at 2 A is a 2 uH part the moment you actually need it.

Also wrote the feedback divider values down properly, so I am not doing that
arithmetic at 1 a.m. with the schematic open.

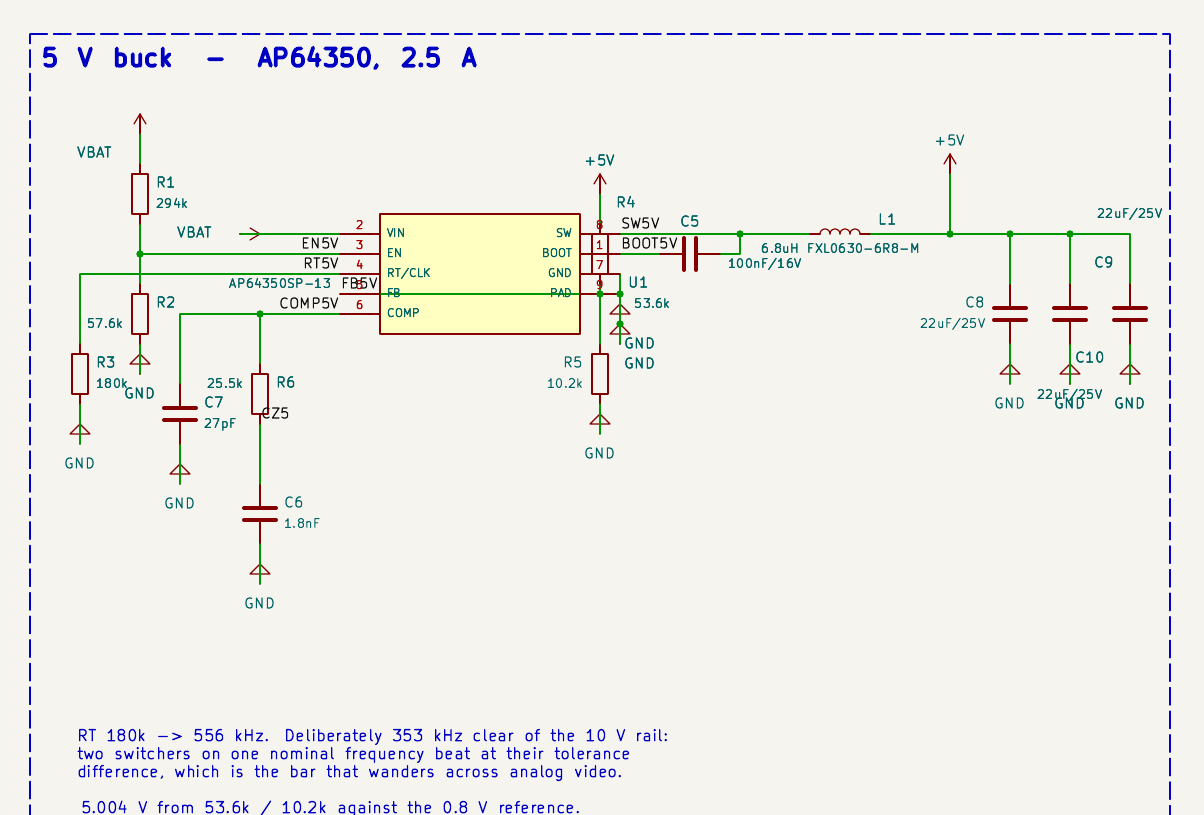
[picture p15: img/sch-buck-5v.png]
the 5 V buck


**Total time spent: 3.1 hours**

# September 08: the 3.3 V rail is wasting half a watt

Went back to the 3.3 V rail I settled yesterday and I don't like it.

The AZ1117 is a linear regulator. It takes 5 V in and gives 3.3 V out, and the
difference does not disappear, it becomes heat. (5 - 3.3) x 0.3 A = **0.51 W**.
On a board that lives sealed inside a carbon frame with no airflow, half a watt
of nothing-useful is a real problem, and it is sitting right next to the gyro,
which is the one part on the board that hates temperature gradients.

The alternative is a small buck. About 90% efficient, so the same rail wastes
about 0.04 W instead of 0.51 W. The obvious objection is that a switching
regulator next to sensitive analog parts is exactly what you are told not to do -
but I am going to have a separate analog rail anyway, fed by a proper low-noise
LDO, and only the gyro and the baro hang off that.

So: buck for the main 3.3 V digital rail, small LDO for the analog rail. The LDO
is deliberately inefficient and that is correct - it buys about 30 dB of supply
rejection on the rail feeding the gyro, for about 25 mW.

Couldn't buy the buck I wanted from either Indian vendor. Noted it as a problem
and left the LDO in for now. That problem is about to get much bigger.

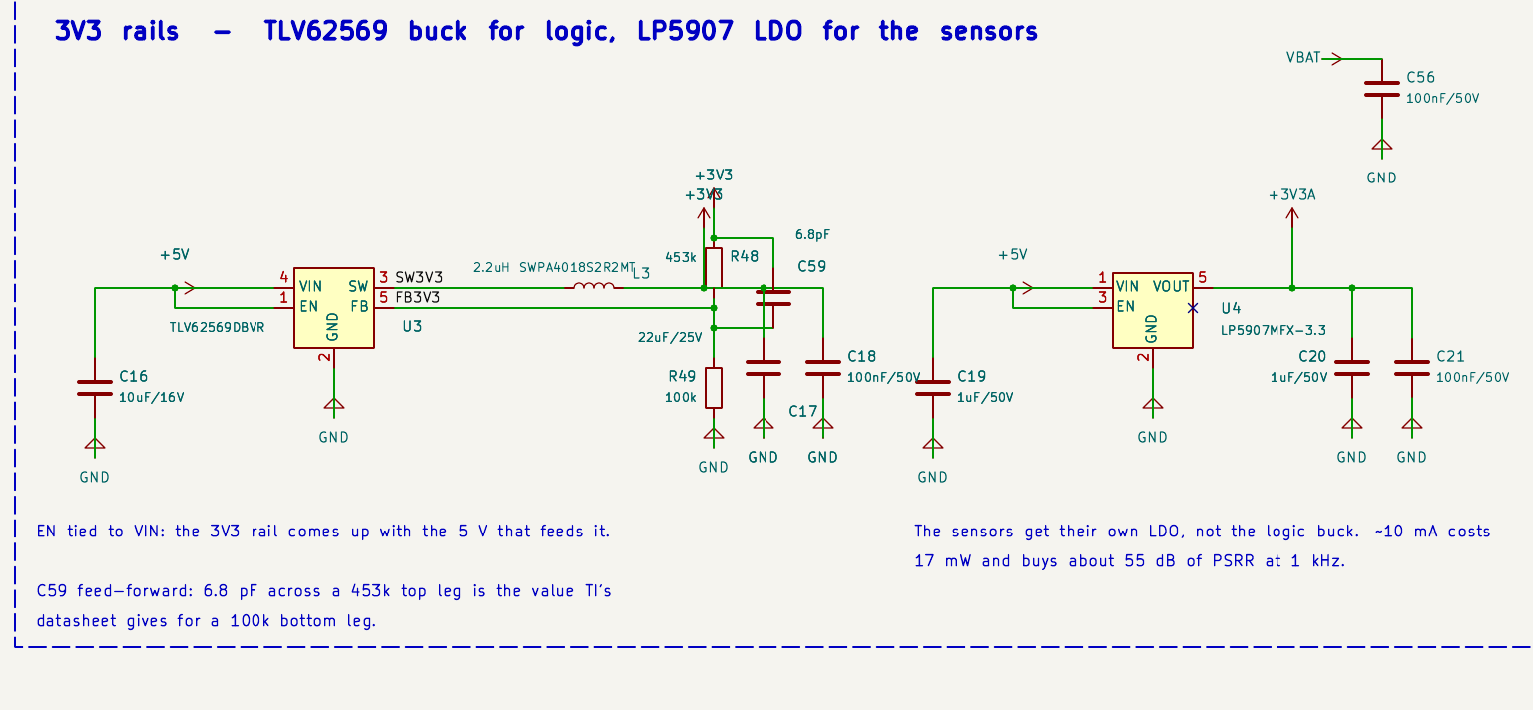
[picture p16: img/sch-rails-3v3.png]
the 3V3 rails - buck for logic, LDO for the sensors


**Total time spent: 2.7 hours**

# September 09: customs, Australia, and giving up on my own clever idea

Spent today adding up what my own sourcing constraint actually costs, and then
threw the constraint out.

The universal gyro footprint I was so pleased with on the 4th exists because the
ICM-42688-P is about 2000 rupees at Robu and the BMI270 is 387 at LionCircuits.
On LCSC the ICM-42688-P is about 180. The footprint trick saves 1612 rupees a
board against a price that only exists because of where I am buying. The clever
part of my design was clever about a problem I invented.

Same story all the way down the BOM. The OSD is not a DNP footprint on LCSC, it
is C82351, in stock, and I can just fit it. The 3.3 V buck I couldn't get is
available. Six parts change and every single one improves.

So: JLCPCB, assembled. Which means dealing with the import side.

**And the import side isn't really about the money.** JLCPCB into India means
duty plus IGST on top of the board price, and then customs clearance, which
nobody can give you a date for. Two to three weeks is normal. Sometimes it just
sits.

I have family in Australia, and I looked seriously at shipping the batch there
and carrying it back next time somebody travels - postage to AU is cheaper and
faster than to IN, and it arrives as a used device in somebody's bag rather than
as an import. Then I worked out what that actually means for a project like this.
I would be waiting on somebody else's flight to get revision one, and if revision
one has a mistake in it - it will - then revision two waits for the flight after
that. A two-week customs queue I can plan around. A three-month travel dependency
I cannot.

So it ships to India, duty paid, and I build the delay into the plan instead of
routing around it. One consequence, and it shapes everything after this:
**I get one shot at the first batch.** Ordering twice costs me a month of
calendar, not 2000 rupees. That is why the back half of this journal is me
reviewing the board instead of drawing it.

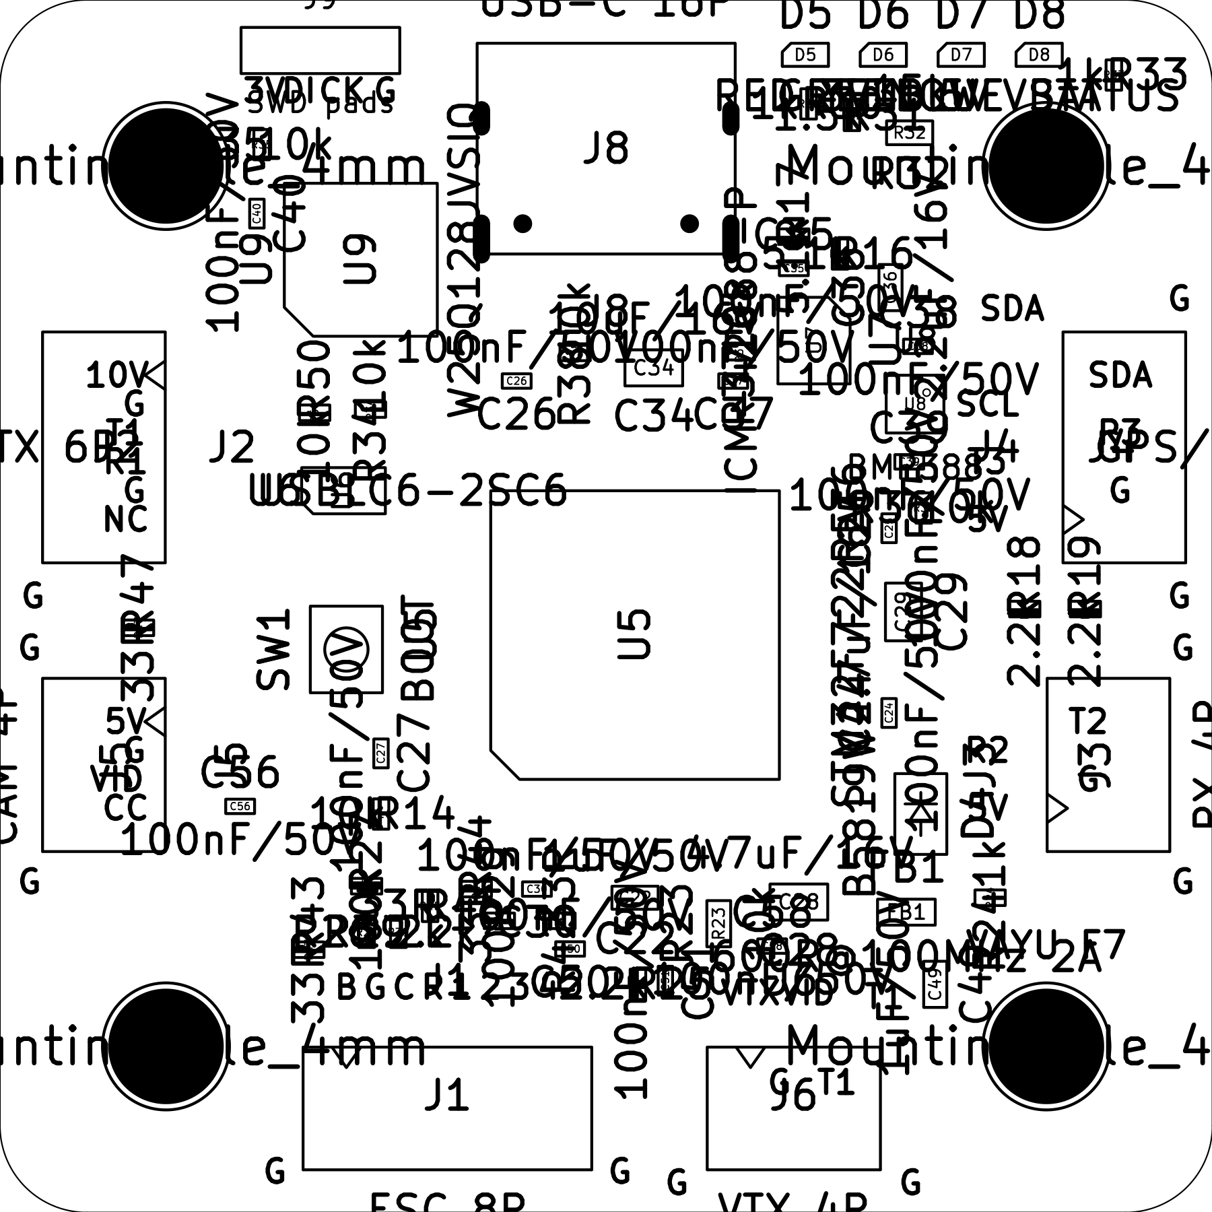
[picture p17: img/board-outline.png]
board outline against the footprints


**Total time spent: 3.2 hours**

# September 10: re-sourcing everything

Six parts changed today and every one of them rippled.

**The bucks: TPS54540 to AP64350.** The TPS54540 is asynchronous - it needs an
external catch diode, and that diode drops about 0.5 V for the whole off-time.
The AP64350 is synchronous, so a low-side FET replaces the diode. At 5 V / 1 A
from 4S that is roughly 89-92% efficient instead of low 80s, and it deletes two
diodes and their footprints. 3.8-40 V in, 3.5 A out, SO-8EP with a thermal pad.

**The 3.3 V rail: AZ1117 to TLV62569.** Finally. The half-watt problem from the
8th is gone - 2 A buck in SOT-23-5, about 90% efficient, and the whole thing
including its inductor is physically smaller than the old SOT-223 was on its own.

One thing I nearly got wrong and want to write down: the TLV62569's feedback
reference is **0.6 V**, not 0.8 V like the AP64350. Same board, two regulators,
two different references. Get that backwards and the divider that should give
3.3 V gives 4.4 V and the MCU is dead. I put both numbers on the schematic as
text so future me can't misremember them.

**The gyro: BMI270 to ICM-42688-P.** At 180 rupees I can fit the better part. The
universal footprint stays, because it costs nothing and is now insurance rather
than a cost lever.

**The baro: BMP390 to BMP388.** I wanted the 390. No stock at the quantity I
need. Same family, same footprint, same address scheme, marginally worse noise.
Second time this project that "better part" has lost to "part that exists".

**The OSD goes from DNP to fitted.** C82351.

**The VTX rail: 9 V to 10 V.** Both numbers are arbitrary - HD VTXs take 7-26 V.
10 V gives more headroom over the VTX's own regulator dropout without pushing the
duty cycle anywhere awkward on 4S.

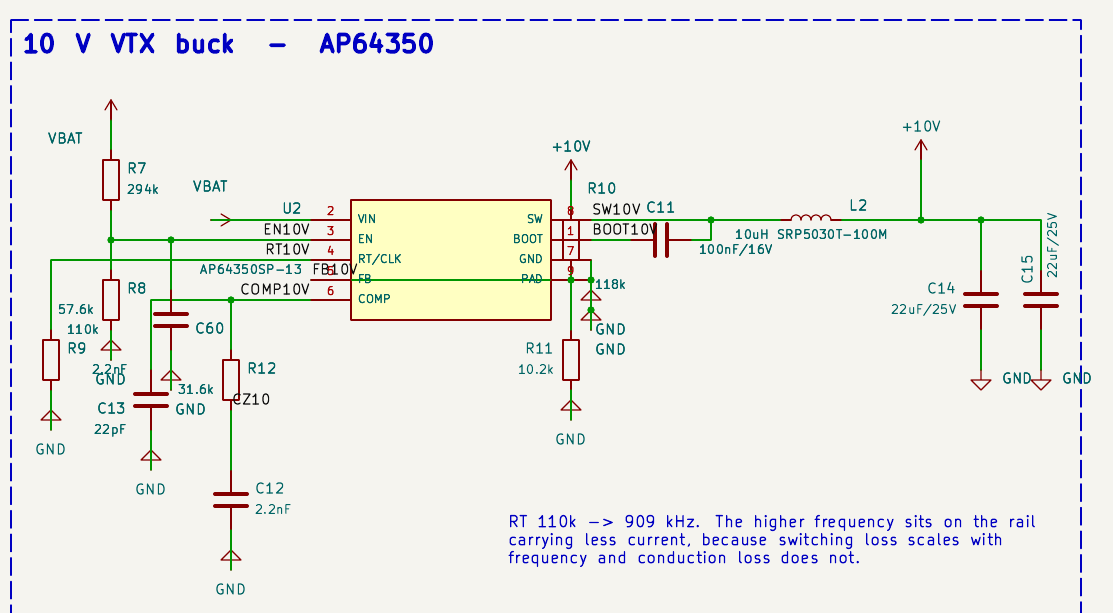
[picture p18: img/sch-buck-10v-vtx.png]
the 10 V VTX buck


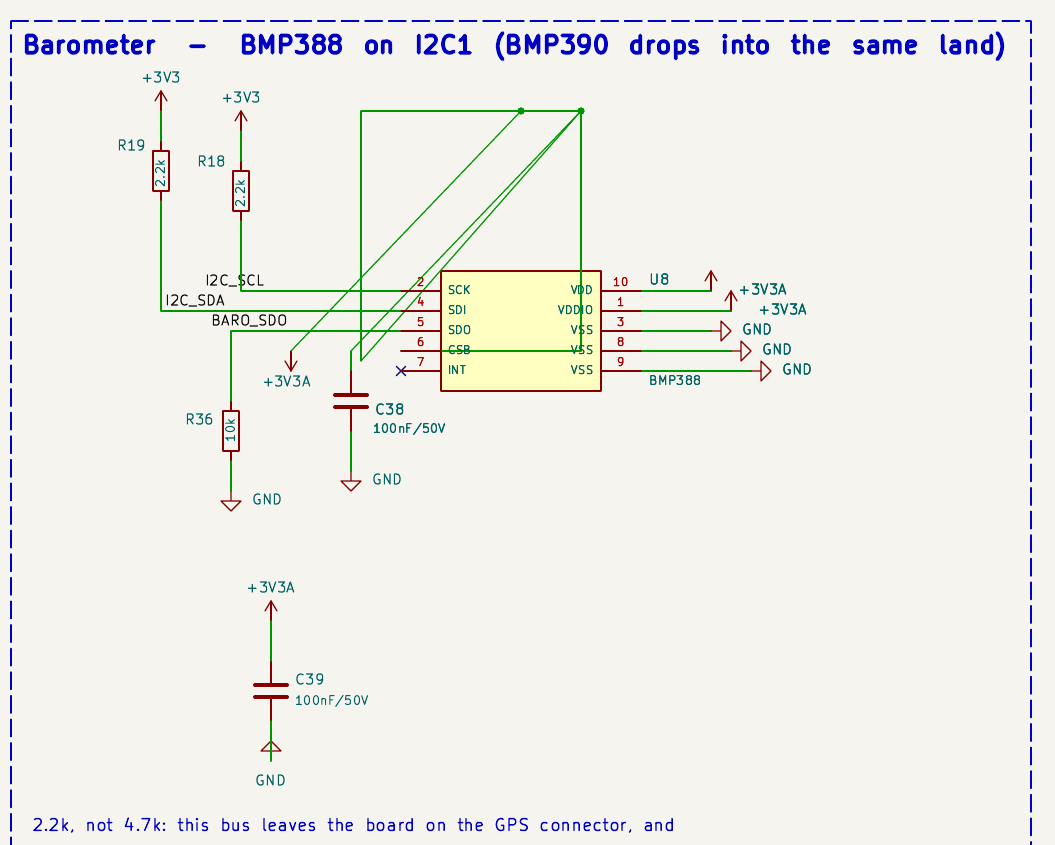
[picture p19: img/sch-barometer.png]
the barometer, with its pull-ups on the analog rail


**Total time spent: 3.1 hours**

# September 11: datasheets, and what each chip drags along with it

Today was pure reading. Every chip on the BOM, and the question for each one is
the same: what does this part need around it that is not obvious from the block
diagram, and how close does it have to sit?

I used AI to speed this up - not to make the decisions, but to pull the relevant
tables out of 200-page datasheets so I could check them myself instead of
scrolling for an hour. It turns a day of hunting into an afternoon of verifying,
and the verifying is the part that actually matters.

The list I ended up with:

- **STM32F722 VCAP_1.** The datasheet gives two values depending on package:
  2.2 uF for packages with two VCAP pins, **4.7 uF for LQFP-64**, which has one.
  Table 19. Undersized here does not fail cleanly - you get a chip that boots most
  of the time and browns out under load.
- **VREF.** Ferrite from +3V3, then 1 uF plus 100 nF, as close to the pin as I can
  physically get them.
- **AP64350 bootstrap.** 100 nF between BST and SW. BST and SW are the two ends of
  one package edge, so the capacitor ties to SW - the node with the fast edge -
  and BST takes the longer side of the loop.
- **AP64350 compensation.** It is externally compensated, Type II: a series R and
  C to ground off COMP plus a small high-frequency cap. Two more parts per rail
  that I had not budgeted board area for.
- **AT7456E crystal: no external load capacitors.** The datasheet says it
  outright - all the capacitors the Pierce oscillator needs are on-chip. I would
  have fitted two out of habit, and a 27 MHz oscillator that is over-loaded may
  simply not start.
- **8 MHz HSE.** Load caps are (2 x CL) - stray, so a 12 pF crystal with about
  4.5 pF of stray wants 15 pF a side. Not 12, not 22.
- **I2C pull-ups go on the analog rail, not the digital one.** Bosch is explicit:
  driving a pin high while VDDIO is off can permanently damage the part. If the
  pull-ups sat on +3V3 and the analog LDO came up later, the baro would get
  exactly that on every single power-on.

The distance rules matter as much as the values. Decoupling within a couple of
millimetres, compensation within three or four, bootstrap under two. Those become
placement constraints later, not suggestions.

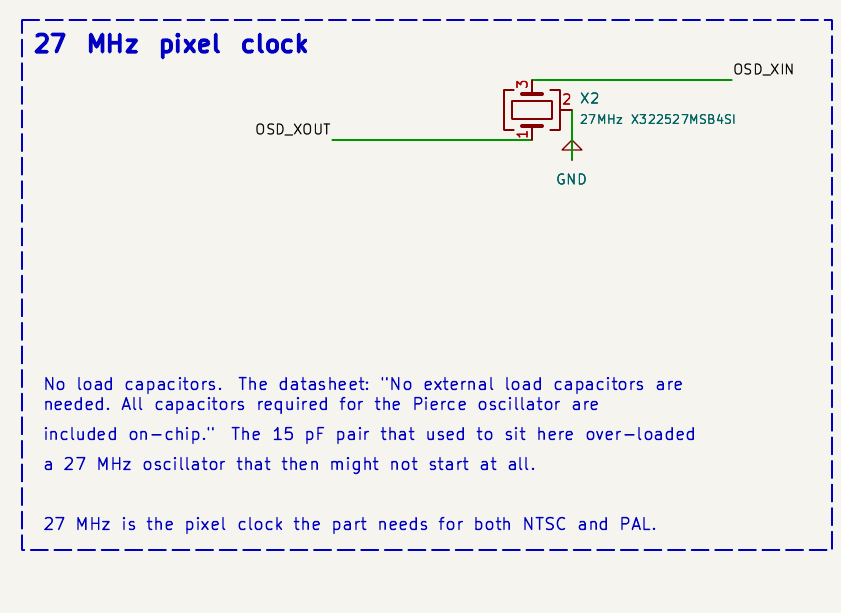
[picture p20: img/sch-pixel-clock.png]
the 27 MHz pixel clock, and the note about load capacitors


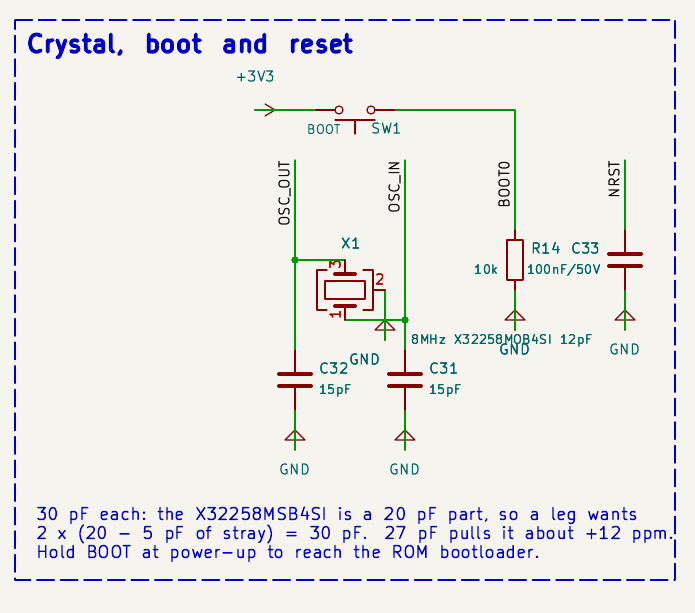
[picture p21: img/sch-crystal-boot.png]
the 8 MHz crystal, boot and reset


**Total time spent: 3.2 hours**

# September 12: the pin map, first pass

Mapping GPIO. This is where an F7 flight controller is actually won or lost, and
I wanted to do it on paper before KiCad had an opinion about it.

The method: group by physical proximity on the package, so that when I place the
MCU the traces fan out instead of crossing over each other. A pin map that is
electrically valid and geometrically stupid costs you a whole layer.

What I had at the end of the day:

- Motors on TIM3 and TIM4, four of them clustered on port B
- Two more motor outputs on TIM8, port C
- SPI1 for the gyro on PA4-PA7, which is the tightest cluster on the package
- SPI2 for the OSD on PB12-PB15
- SPI3 for the flash on PA15 / PB3 / PB4 / PB5
- UART1 on PA9 / PA10 for the VTX
- UART2 on PA2 / PA3 for the receiver
- UART3 on PB10 / PC11 for GPS
- I2C1 on PB8 / PB9, which also goes out to the GPS connector for an external
  compass
- USB on PA11 / PA12, SWD on PA13 / PA14
- ADCs on PC0-PC3

Six motor outputs felt right at the time - a quad with two spare for a hex or a
gimbal. I come back to that.

Everything cross-checked against DS11853 Table 12 for the alternate functions and
RM0431 Tables 26/27 for the DMA streams, because a timer channel with no DMA
stream free is a motor output that cannot do DShot.

the whole sheet

**Total time spent: 2.9 hours**

# September 13: two pins that would have bricked the board

Went back over yesterday's pin map line by line instead of trusting it, and found
two things that would otherwise have shipped.

**The critical one: two of my motor outputs were impossible.** I had motors 7 and
8 on PC10 and PC11. On LQFP-64 those pins have _no timer alternate function at
all_. Not a different timer - none. They can be UART, SPI, SDIO or GPIO and that
is it.

The reflex is "so bitbang them". Betaflight can. **INAV cannot** - I went and read
the INAV source to be sure, and there is no DShot bitbang implementation in it.
So on INAV those two outputs would simply not exist. Fixed by dropping to six
timer-backed outputs and turning PC10/PC11 into PINIO pads, which is what they
are actually good for: switching a camera or a VTX on and off.

**The second one: VCAP_1 again.** I had written 2.2 uF into my notes despite
reading Table 19 two days earlier. It is 4.7 uF on LQFP-64. Changed it, and I am
now suspicious of every value I transcribed rather than copied.

**And the DMA problem.** Six DShot outputs across TIM3, TIM4 and TIM8 all want
DMA streams, and on the F7 TIM3 and TIM4 both live on DMA1 with overlapping
choices. The way out is burst mode (`USE_DSHOT_DMAR`), where one stream serves
all four channels of a timer through the burst register. That is a firmware flag,
not a hardware fix, so I wrote it straight onto the schematic sheet where whoever
ports the target cannot miss it.

The two spare UARTs come out on solder pads on the underside rather than
connectors. Costs me almost nothing in area and means the board doesn't dictate
what you plug into it.

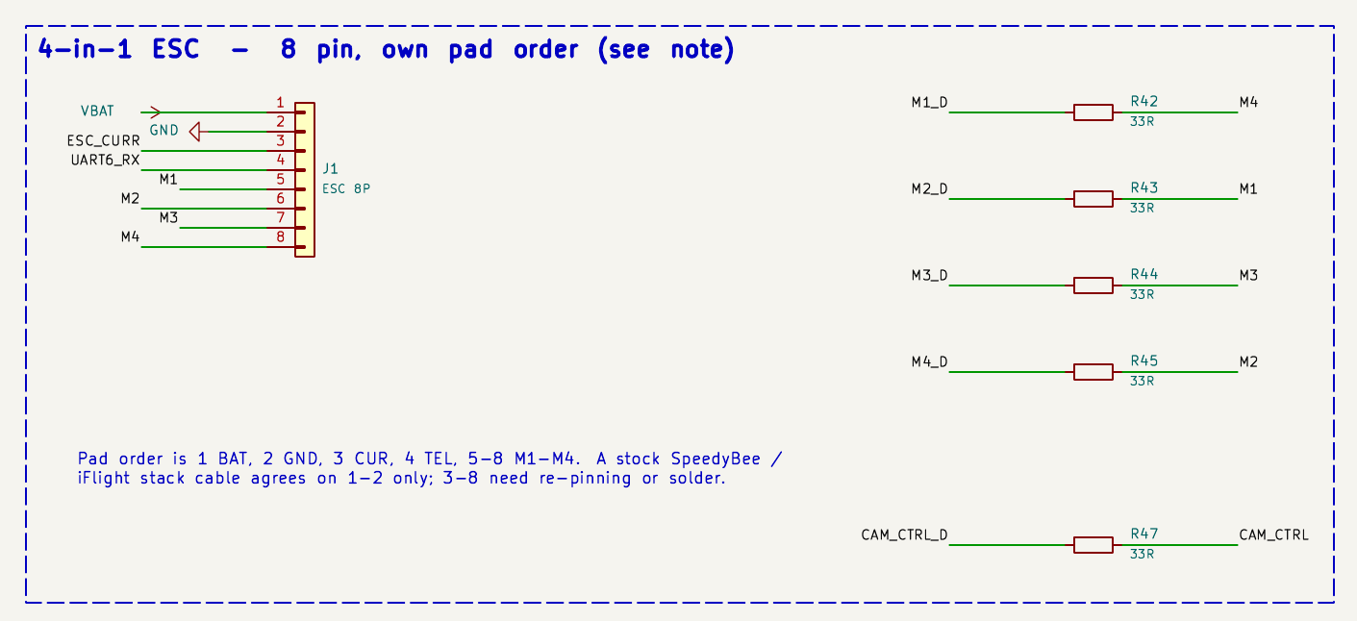
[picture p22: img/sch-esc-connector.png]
the ESC connector and the motor damping resistors


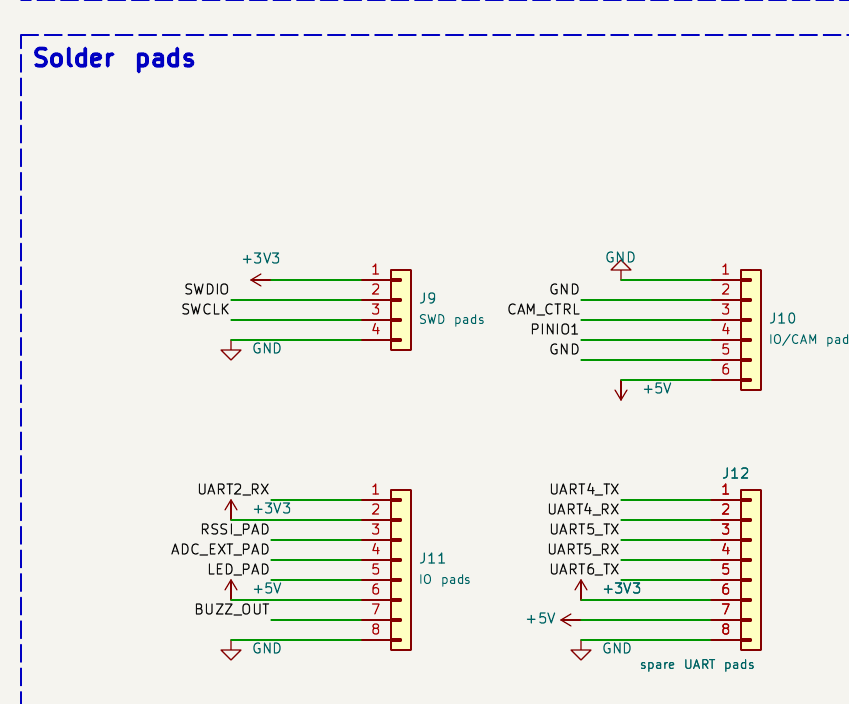
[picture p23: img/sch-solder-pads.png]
the solder pads, where the spare UART comes out


**Total time spent: 3.1 hours**

# September 14: the schematic finally starts looking like a board

Started actually drawing in KiCad. Two things went wrong and both taught me
something.

I kept the power section together, put the MCU in the middle, and worked outward
to the sensors and connectors. That sounds obvious until the sheet is full of
crossing wires and every small change makes the next one harder. The layout is
already influencing the schematic: the gyro gets its own SPI bus, the flash and
OSD stay separate, and the connector pin order is chosen with the eventual
routing in mind.

The first pass also exposed a much less interesting but more dangerous problem.
The regulator's RT/CLK pin and exposed ground pad were sitting in the symbol but
were not actually connected to anything. A regulator with no timing resistor does
not switch, and a regulator with a floating thermal pad has no proper return.
ERC did not make the mistake obvious because the symbol looked complete while I
was skimming it.

I fixed those connections by hand and started checking every pin against the
datasheet, not just trusting a clean-looking page. "The schematic looks finished"
and "the circuit is connected" are two different claims.

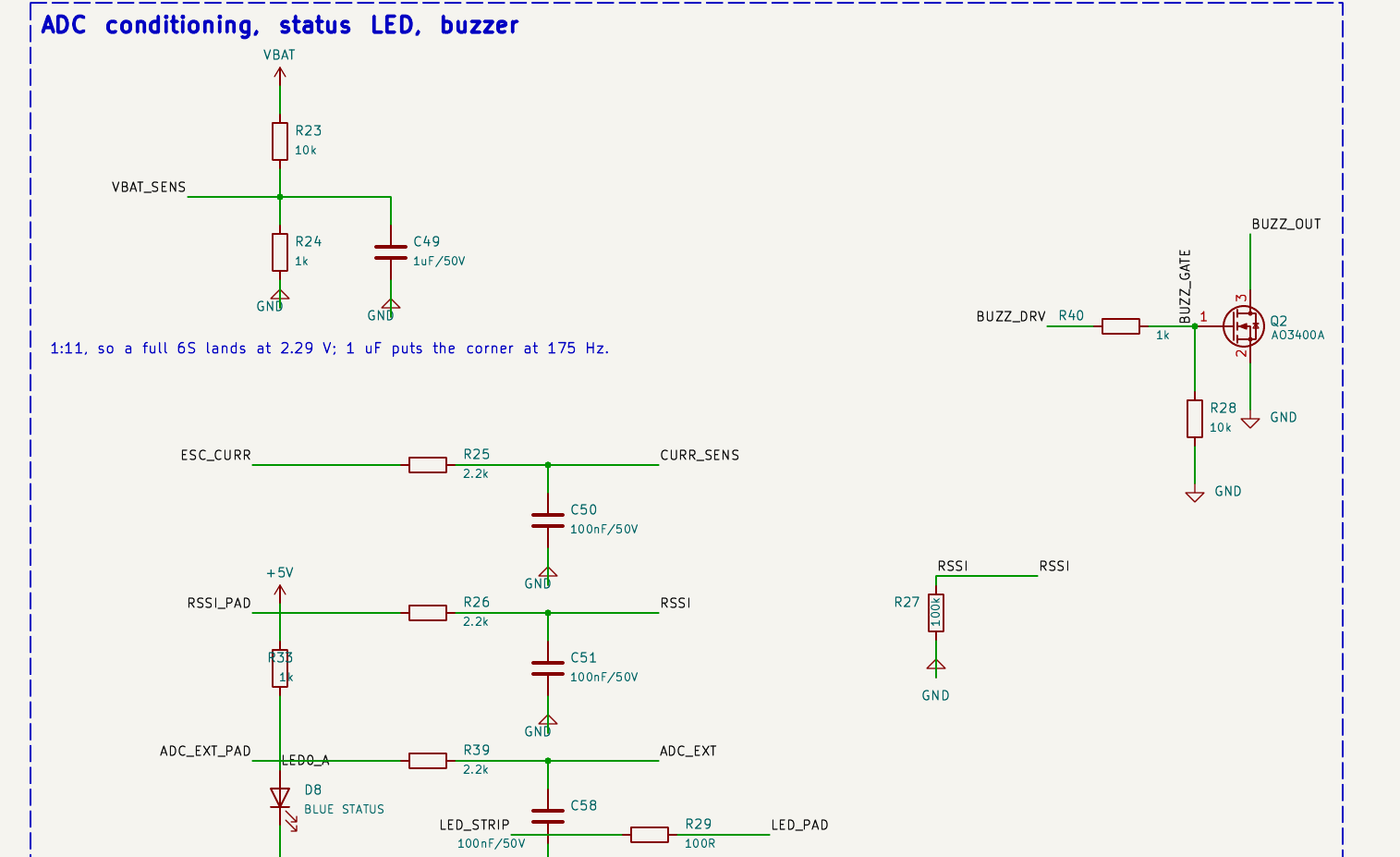
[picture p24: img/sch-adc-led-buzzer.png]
the ADC conditioning, status LED and buzzer block


**Total time spent: 3.3 hours**

# September 15: reading my own schematic like I want it to fail

Spent today reviewing yesterday's schematic as if somebody else had drawn it and
I were being paid to find the mistake. Found fourteen things, two of which were
serious.

The two that mattered:

- A **feedback divider tied to the regulator's output node instead of the FB
  pin.** On a schematic those look identical if you are skimming. In silicon it is
  a regulator running open loop at maximum duty cycle, which on the 10 V rail
  means the VTX sees battery voltage.
- **Flash WP and HOLD, and the baro SDO, tied hard to rails.** ERC flags that as a
  bidirectional pin driven by a power output, and I had been about to suppress the
  warning. The right fix is 10k straps instead of hard ties, which is also just
  better engineering - now I can change the flash write protection or the baro's
  I2C address with a resistor instead of a knife.

The other twelve were smaller: missing decoupling on two supply pins, a
compensation cap on the wrong side of a resistor, an LED with no ballast, a
reverse-polarity FET drawn with its body diode the wrong way round.

Ended the day at 0 ERC errors and 0 warnings, which I am now aware means less
than I thought it did yesterday.

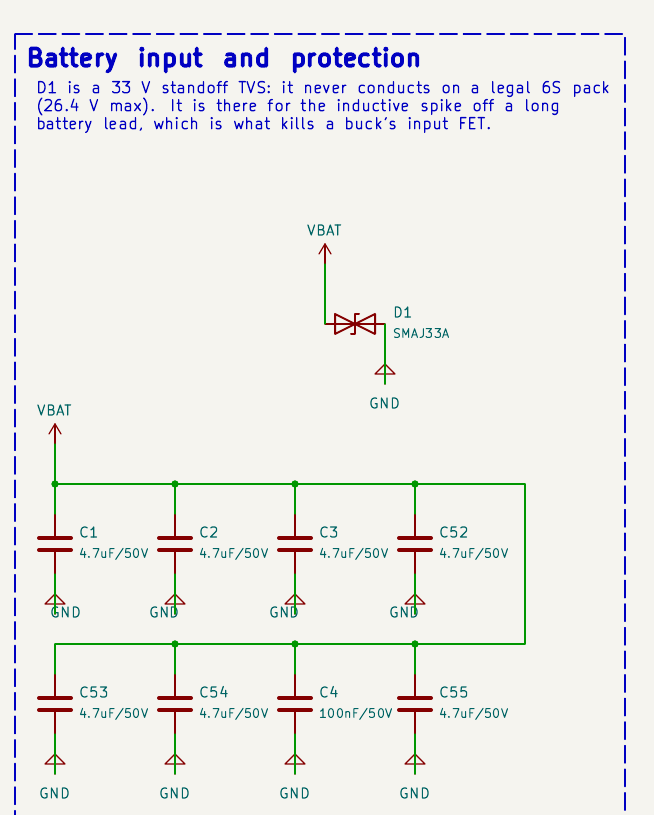
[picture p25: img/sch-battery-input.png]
battery input and protection


**Total time spent: 2.1 hours**

# September 16: 38 x 38 doesn't fit, and the first placement embarrassed me

Long day. Took the schematic to a board and found out my board was too small.

I had planned 36 x 36 mm and it does not fit. I proved it rather than eyeballing
it - wrote a check that sums courtyard area per side and compares it against
usable board area once you subtract the four mounting-hole keepouts and the
connector ring. 36 x 36 needs about 118% of the space it has. 38 x 38 gets it
under 100% and that is what I laid out.

(It ends up at 42 x 42 eventually. The connector ring is what kills you - six
JST-SH housings round the edge, each needing its own approach clearance, and none
of that area is usable for parts.)

**Then the first placement embarrassed me.** I had placed the parts so that the
courtyards did not overlap, which is a very low bar. The 10 V rail's compensation
capacitor ended up **15 mm from its regulator**. It was legal in the drawing and
completely wrong electrically. The input loop of a buck converter is the highest
di/dt node on the whole board, and a placement that treats every millimetre as
equal does not understand that.

I moved both power stages by hand and kept each one as a tight switching loop:
input cap, regulator, inductor, output cap, with the return path directly under
the loop. That is the kind of placement decision a clearance check cannot make.

Last thing before I stopped: **a through-hole pad landing on a part on the other
side of the board.** The USB-C connector has through-hole shield legs and one of
them came down straight through a capacitor pad on the bottom. DRC does not catch
that, because on a two-sided board those are two different layers and both are
perfectly legal on their own. I checked the through-hole pads against the parts
on the opposite side by hand and found two more collisions before they became a
fabrication surprise.

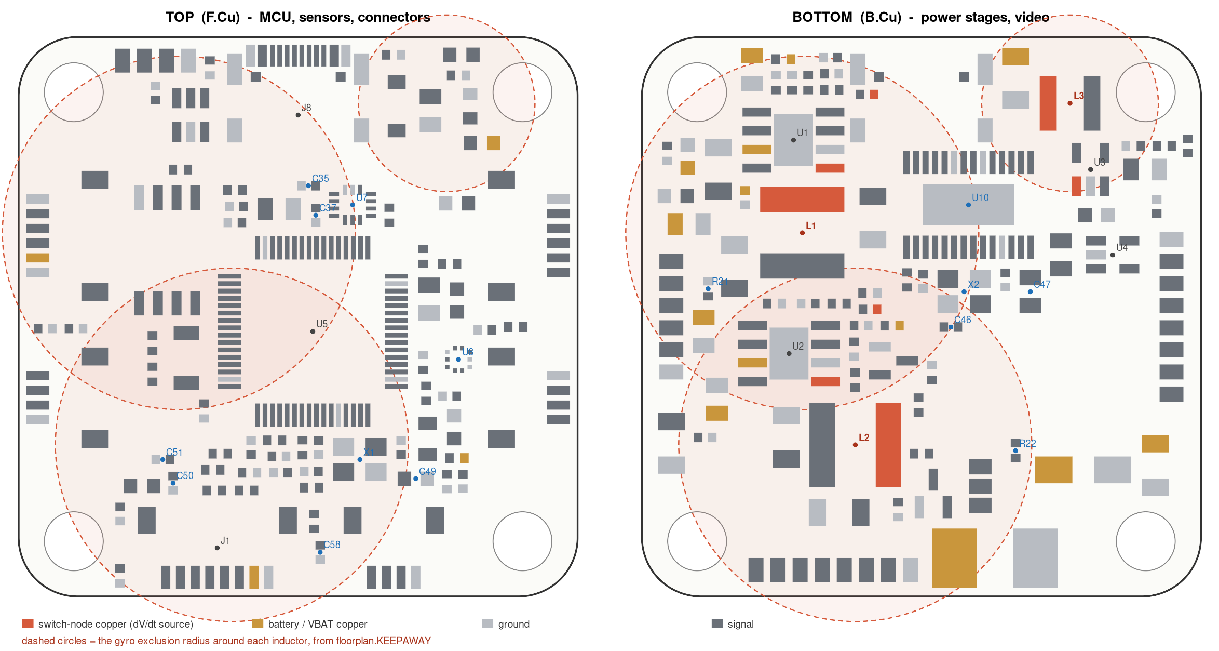
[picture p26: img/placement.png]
the hand floorplan, both sides


**Total time spent: 3.8 hours**

# September 17: five sheets or one, and four footprints that didn't exist

Redrew the schematic twice, then made the board routable.

I had built it hierarchically first - five pages, power / MCU / sensors / video /
IO, with a block diagram on the root sheet. Textbook, and I hated using it. The
problem is that a flight controller has almost no internal structure. The MCU
touches everything. Every sheet ended up with eight hierarchical pins on it and
half my time went on flipping pages to answer "where does this actually go".

So I redrew it as **one A1 sheet with nineteen named sections** - boxed regions
with titles, laid out roughly where the parts sit on the board. Power bottom
left, sensors top right, video along the bottom, connectors round the edge in the
order they physically appear. Big sheet, but you can follow a net across the whole
design without changing page.

Also fixed something that had been wrong since the first layout: **three of the
side connectors were mirrored.** The nets were right, but the JST housing opened
toward the middle of the board, so the wires would come out, turn 180 degrees and
run back over the components. On a board this size there is nowhere for that loop
to go. I only caught it by exporting the placement as a picture and looking at it
instead of reading the netlist.

And the power stage was twice as tall as it needed to be - two separate blocks
stacked vertically, each with its own input caps strung out beside it. Redrawn as
two loops sharing one input bank, which halved the height of that region and
freed the space the 10 V rail needed to reach the VTX connector.

Then the netlist import failed on four parts. "Footprint not found", which is
accurate and useless. All four were footprints I had named in the schematic but
never drawn into the project library - both bucks' SO-8EP, the crystals' 3225,
and the USB-C. I had been referencing KiCad's stock libraries by name in some
places and my own in others. Drew all four properly from the manufacturers'
drawings. New rule: if it is on the board, its footprint lives in this repo.

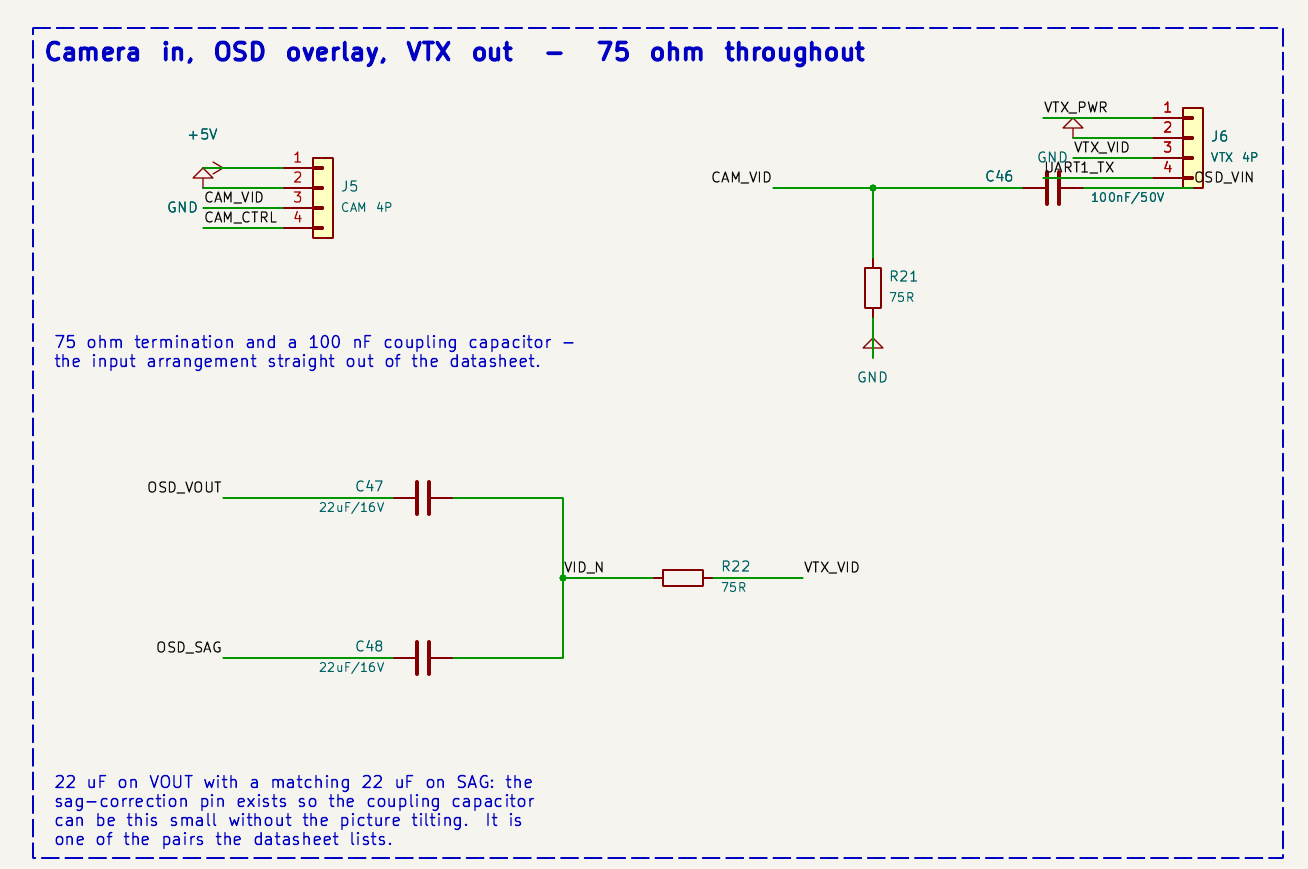
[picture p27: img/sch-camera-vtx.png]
the video path - camera in, OSD overlay, VTX out


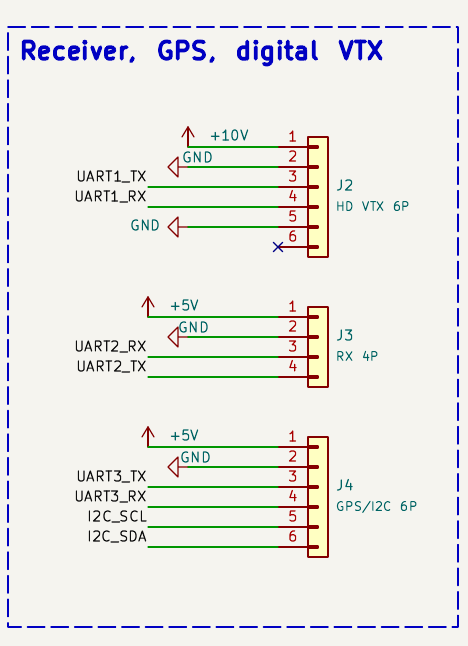
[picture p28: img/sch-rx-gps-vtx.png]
receiver, GPS and digital VTX connectors


**Total time spent: 3.4 hours**

# September 18: routing it by hand

Routing. This board has maybe fifteen nets where the geometry _is_ the design -
the two switching loops, the gyro's SPI, the video path - so I routed those
sections by hand and paid attention to every return path. The rest of the board
was slower, but at least I knew why every track was where it was.

The stackup, decided before the first track: **F.Cu signal / In1.Cu solid ground /
In2.Cu signal plus ground pour / B.Cu signal.** The rule I gave myself is that
nothing crosses In1. Ever. Every fast edge on the board has an uninterrupted
return path directly under it, and the moment you slot that plane to squeeze a
track through, the return current goes the long way round and you have built a
loop antenna instead of a trace.

Order of work, because it matters:

1. The two power loops first, while there was still empty copper to do them
   properly. Input cap to FET to inductor to output cap, and the return stitched
   straight down to In1 underneath rather than run around.
2. Then the gyro. SPI1 kept short and away from both inductors - the floorplan
   has a keepaway circle drawn round each one for exactly this.
3. Then the video path. Camera in, through the OSD, out to the VTX connector -
   75 ohm-ish throughout and as direct as the board allows, because every
   millimetre and every via in that path is latency and reflection I don't get
   back.
4. Everything else last, into whatever is left.

The MCU escape ring is the hard part. LQFP-64 at 0.5 mm pitch means 64 pins
leaving a 10 mm square, and the ring of vias that gets them out eats most of the
area around the chip. Half of today was finding paths through it.

Ended at 2897 track segments and 419 vias over four layers, then laid the zones
and set the net classes properly - power nets on their own widths rather than the
default, and zone priorities so the ground pour doesn't fight the 10 V rail.

One thing I noticed while tidying: I have no revision marking on the silkscreen
at all. Not a problem now. A very big problem when there are three prototype
batches on the desk and no way to tell them apart. Added it to the list.

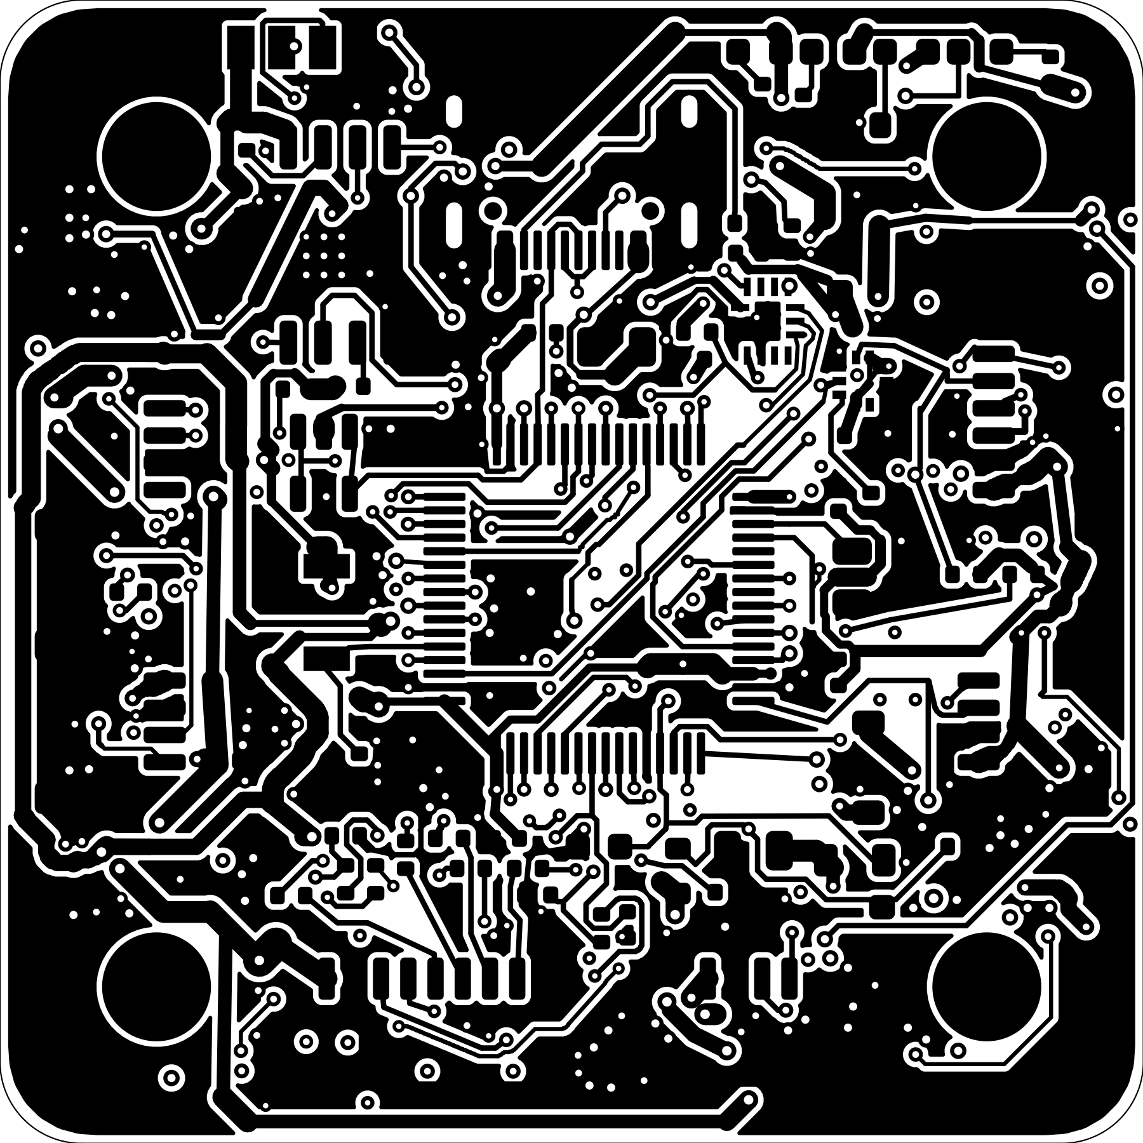
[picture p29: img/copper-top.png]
top copper


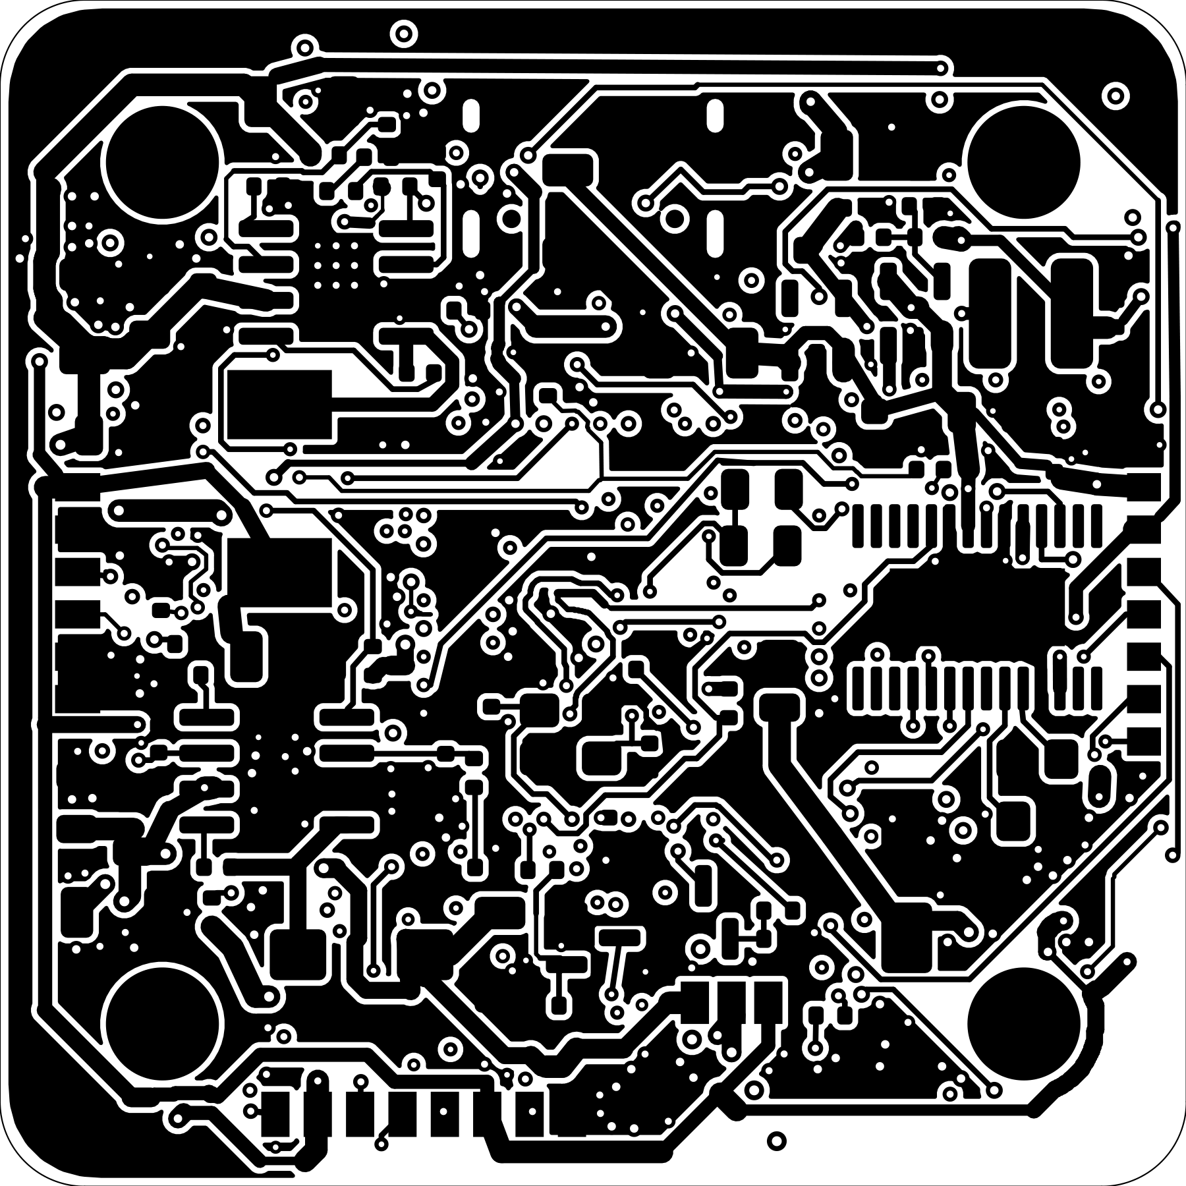
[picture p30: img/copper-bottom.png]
bottom copper


**Total time spent: 2.2 hours**

# September 19: reading it back cold

Deliberately left it alone for a day and came back to it cold, because I cannot
review something I drew an hour ago - I read what I meant instead of what is
there.

Then I wrote a status document describing the board as if I were handing it to
somebody else. That trick works on me. I can skim my own work, but I cannot write
a description of it without noticing what I am glossing over.

Three things I only saw because I had to write them down:

- **I could not state the input current limit.** I knew the copper was fine; I had
  checked every trace width against IPC-2221. I had never once asked what the
  _connector_ could pass. That turns out to be the number that constrains the
  entire design, and I get to it on the 21st.
- **The board is 38 x 38 and I don't know if that is final.** It is not. Once the
  full connector ring was laid out with proper approach clearances it went to
  42 x 42.
- **No revision marking**, as noted yesterday.

Writing "this board can deliver X" and being unable to fill in X is the cheapest
way I know to find a hole in my own understanding.

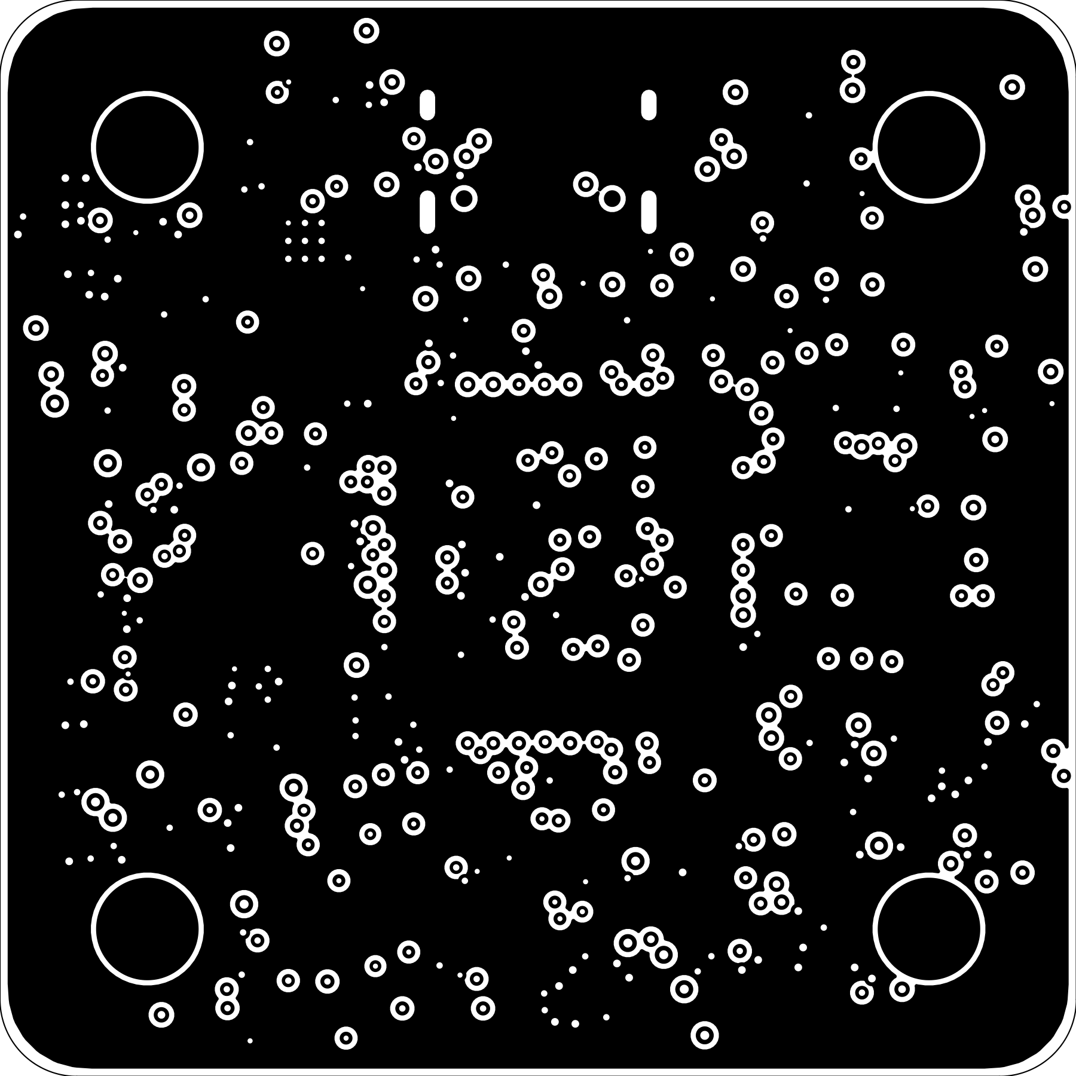
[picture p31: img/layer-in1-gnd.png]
In1 - the solid ground plane, nothing crosses it


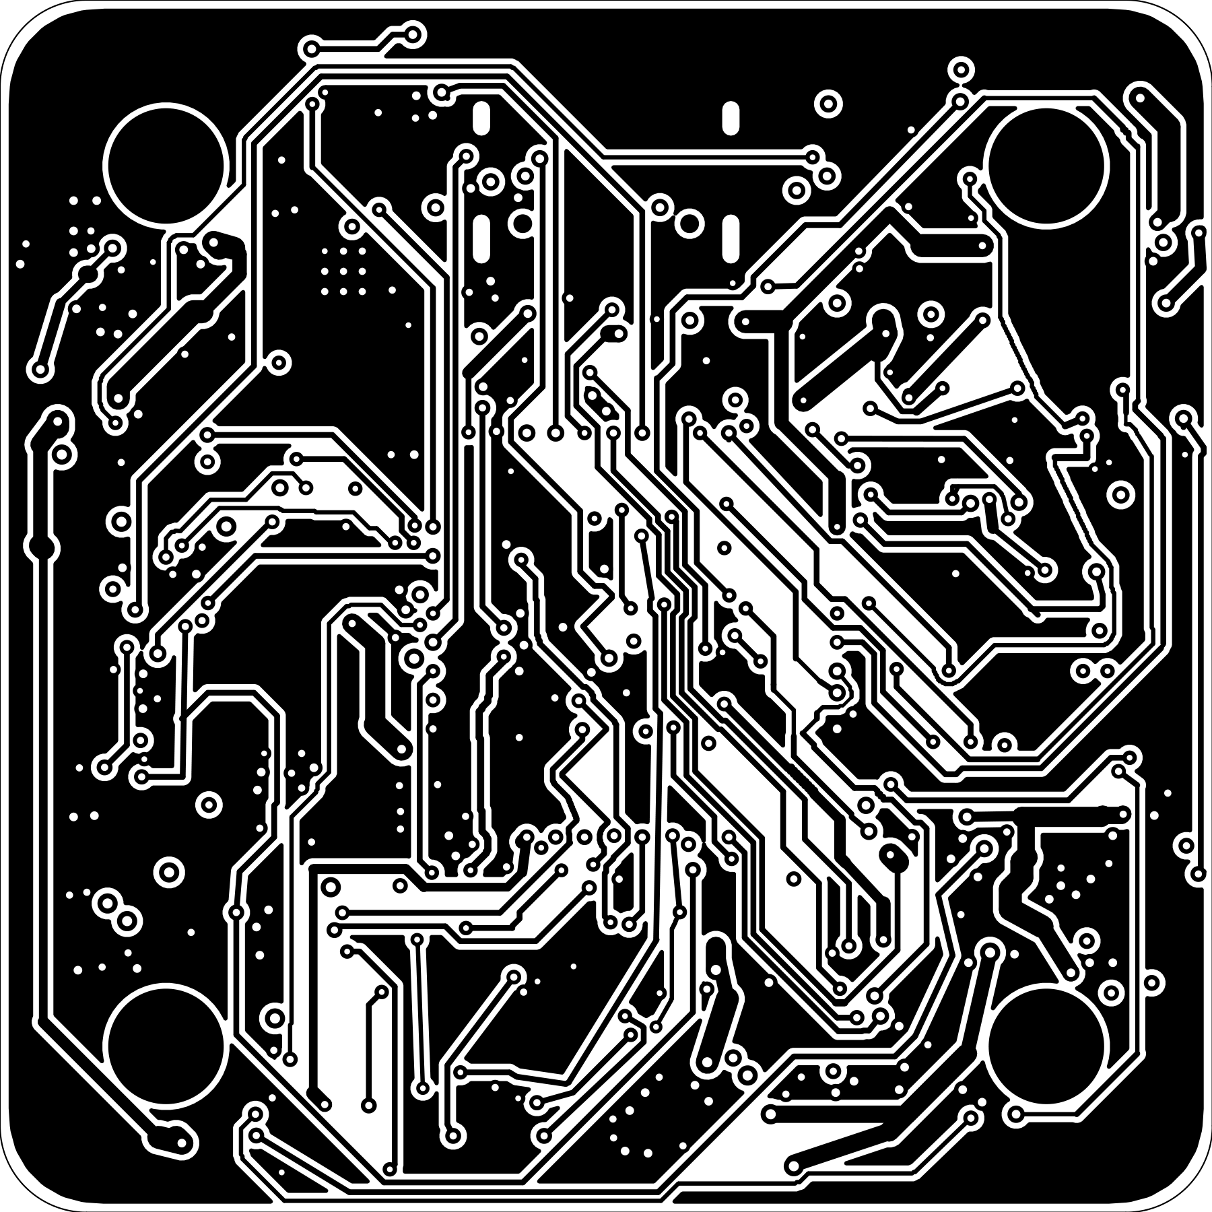
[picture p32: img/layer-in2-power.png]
In2 - signal plus ground pour


**Total time spent: 2.1 hours**

# September 20: 5.5 out of 10

Full inspection today, scored honestly, and it came out **5.5 out of 10**. Not a
fun morning.

I rendered the silkscreen for both sides and went through the whole board against
JLCPCB's published capabilities rather than KiCad's defaults, which is where most
of this came from.

**Vias inside reflowed pads. Eighteen of them.** A via in a pad that gets solder
paste wicks the solder down the barrel, and you get a joint that looks perfect
and isn't. Worst offender was a 0.55 mm via sitting in the gyro's 0.68 x 0.25 mm
pad.

**Annular rings under the fab's minimum. 276 vias at 0.100 mm** against JLCPCB's
0.130 mm. Every one of those is a potential open circuit, and my DRC was silent
about all of them, because I had set my own rules looser than the fab's. That is
the lesson of the day, really: **DRC only tells you what you told it to care
about.**

**Rails too narrow.** The 10 V feed to the VTX connector is 0.250 mm, which is
about 1.19 A by IPC-2221 at a 20 degree rise, feeding a rail I sized for 2 A. The
5 V trunk is 0.200 mm.

**Silkscreen over pads**, in seven places, which gets clipped away in
manufacturing.

Scoring it as a number is the useful part, because it stops you negotiating with
yourself. A board with 276 undersized vias is not "nearly there with a few items
outstanding". It is 5.5, and 5.5 does not ship.

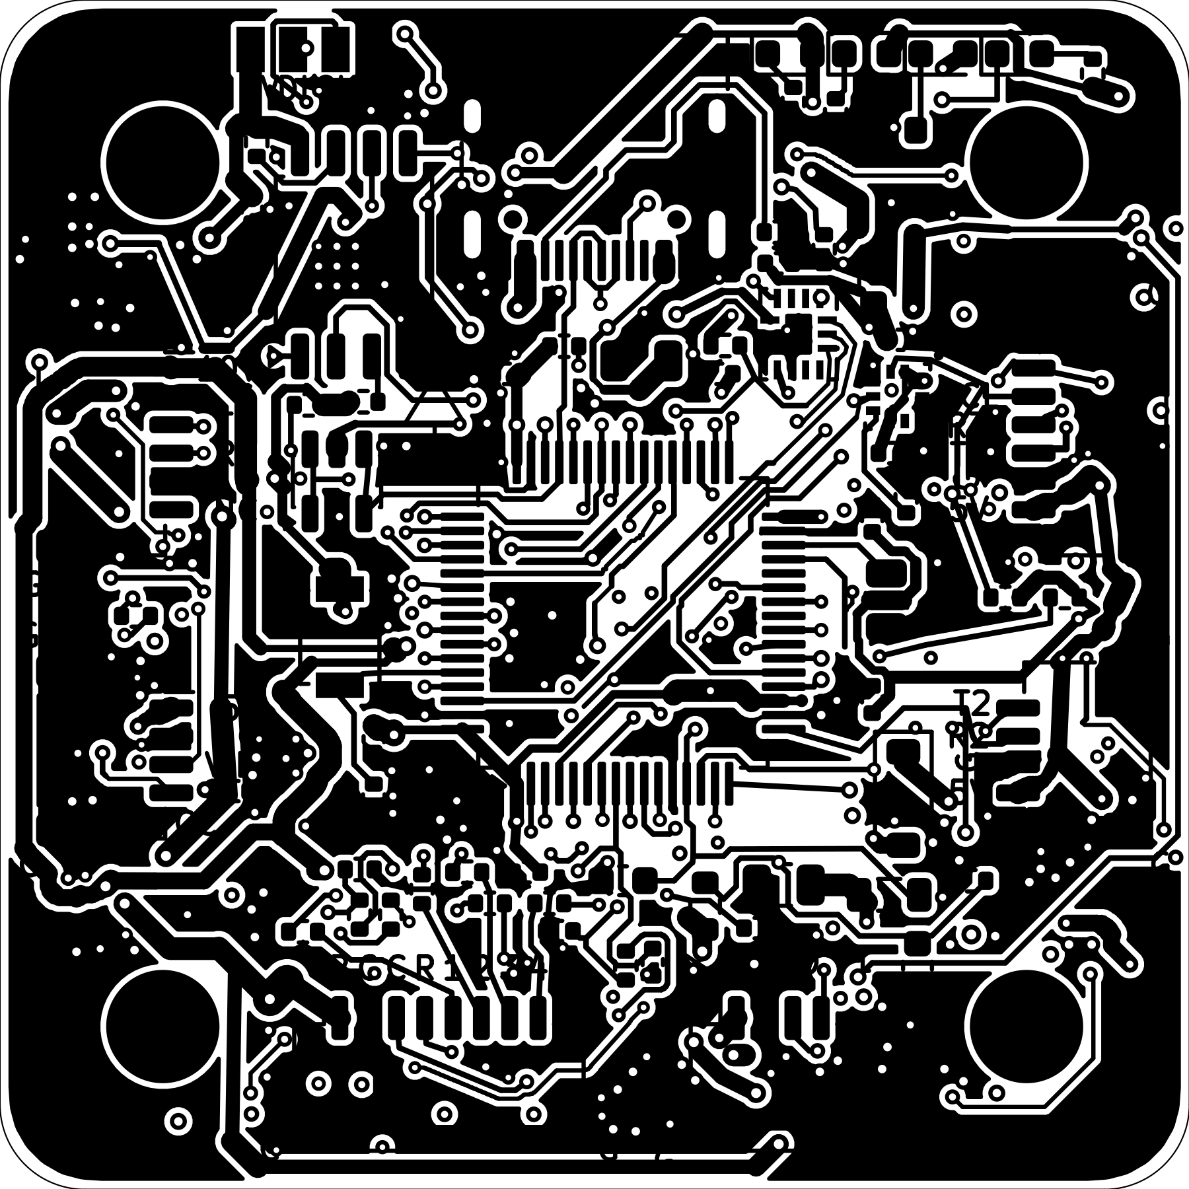
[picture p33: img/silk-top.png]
top silkscreen


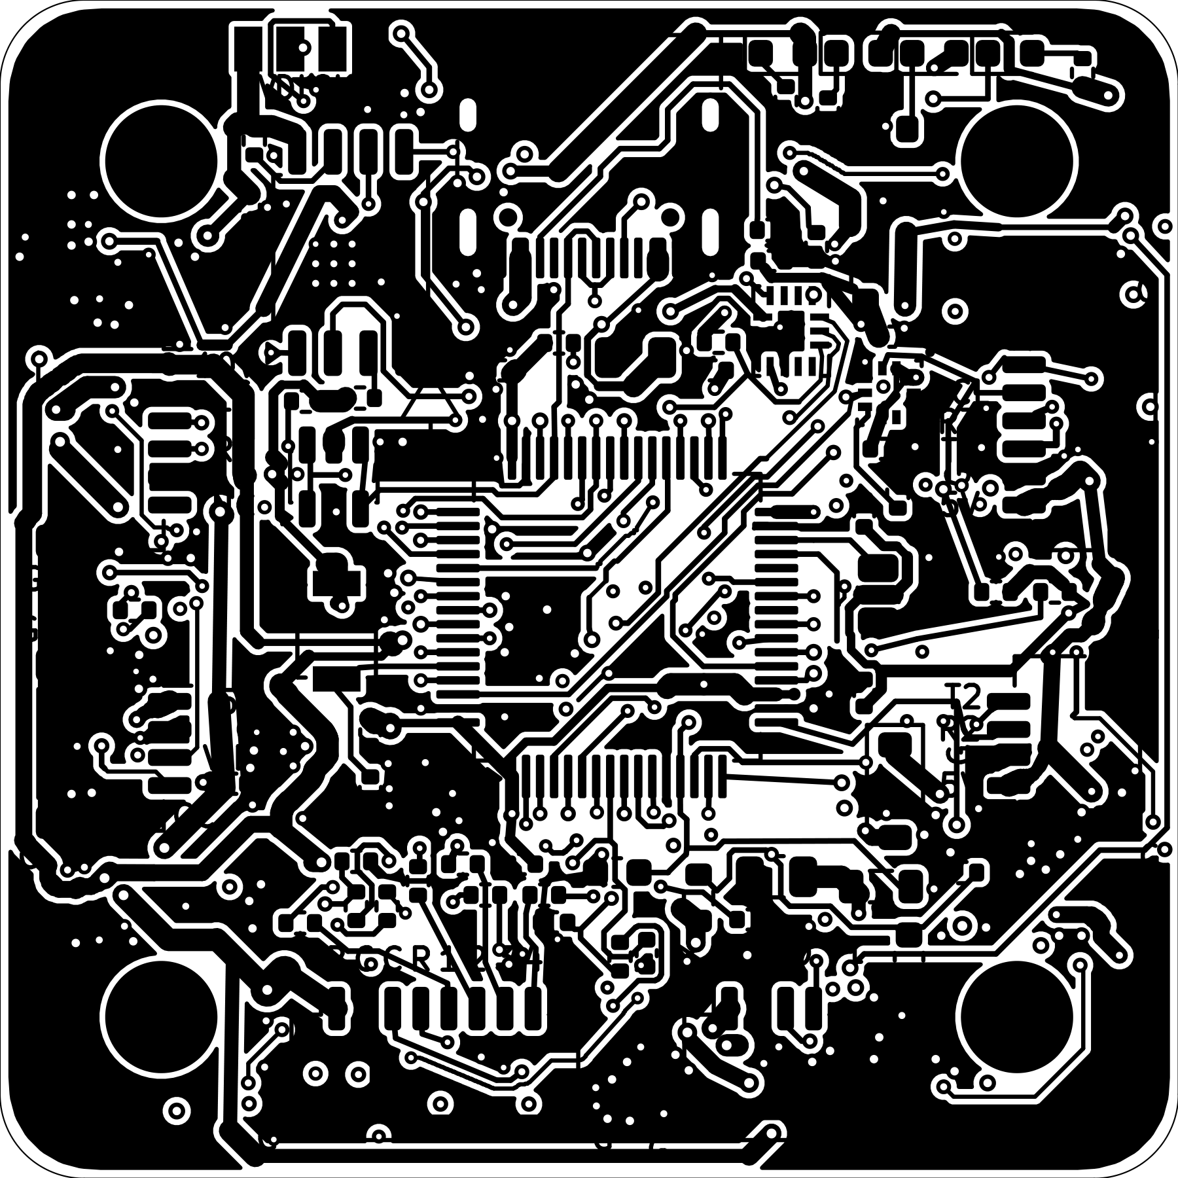
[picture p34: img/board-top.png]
top side


**Total time spent: 3.4 hours**

# September 21: R2, R3, R4 - rules, rails, and twelve dots that weren't there

Three revisions in a day. Sorted yesterday's list into things with exactly one
correct answer, things that need a decision, and things I am going to have to
live with - because fixing a cosmetic problem badly is how you break a working
board.

**R2 was the mechanical half.** Design rules first, because most of the
violations were invisible until the rules were right: annular ring 0.125 mm,
through-hole 0.20 mm, track 0.10 mm, copper-to-edge 0.20 mm. Then grow all 276
undersized vias until their rings meet spec. A via at 0.45 mm diameter on a
0.20 mm drill gives exactly 0.125 mm of ring, and 0.20 mm drills carry no
surcharge as long as the pad is 0.45 mm or bigger, so that fix cost nothing but
the time.

**R3 was the fab rules and the rails.** 10 V went from 0.250 to **0.600 mm**
(2.21 A), 5 V from 0.200 to **0.400 mm** (1.66 A). Neither fits as a single trace
on this board, so both are parallel bridges - two tracks on different layers
stitched together with vias. Seven of the eighteen in-pad vias moved out. DRC hit
**0 violations** for the first time.

Also read JLCPCB's process rules properly rather than from memory, and found I
had been designing to their _non-plated_ slot minimum of 1.0 mm when the plated
minimum is 0.35 mm, and that parts on both sides puts the job in Standard PCBA
rather than Economic, which has a 70 x 70 mm minimum panel. My board is 42 x 42,
so it gets ordered as a 2 x 2 panel whether I like it or not. Better to know that
now than at checkout.

**Then I critiqued R3**, looking specifically for things that pass DRC and are
still wrong, and found the one that matters most:
**the input connector.** VBAT enters on one JST-SH contact rated 1 A and returns
on another. I had been checking copper widths this whole project and the copper
was never the limit. 1 A means 11 W on 3S, 15 W on 4S, 22 W on 6S. An HD VTX
drawing 12 W is fine on 6S, marginal on 4S and over the limit on 3S. Not a DRC
violation. Would have been a surprise in the air.

**R4: four motors, not six.** It is a quad. Six outputs tied up two timers and
two DMA streams for pads nobody will solder. And cutting back revealed that motor
4 was on **PB1**, to which there is _no route on this board_ - not a hard route,
none; every path at every width blocked by the escape ring. I found that by
trying to route it and failing. Moved to PC8, which routes in 14.9 mm with zero
vias.

Then the thing that nearly ended the project. ERC had been showing 16 errors that
I had written off as noise. They were not noise. **Twelve wires
ended on the interior of another wire with no junction dot**, and KiCad does not
treat that as a connection. What was disconnected: the feedback tap on the 5 V
rail, on the 10 V rail, on the 3V3 rail, and **both terminals of the 8 MHz
crystal.** Three regulators running open loop and an MCU with no clock. I had
dismissed the one check that was telling me the truth, because I had decided in
advance what its errors meant.

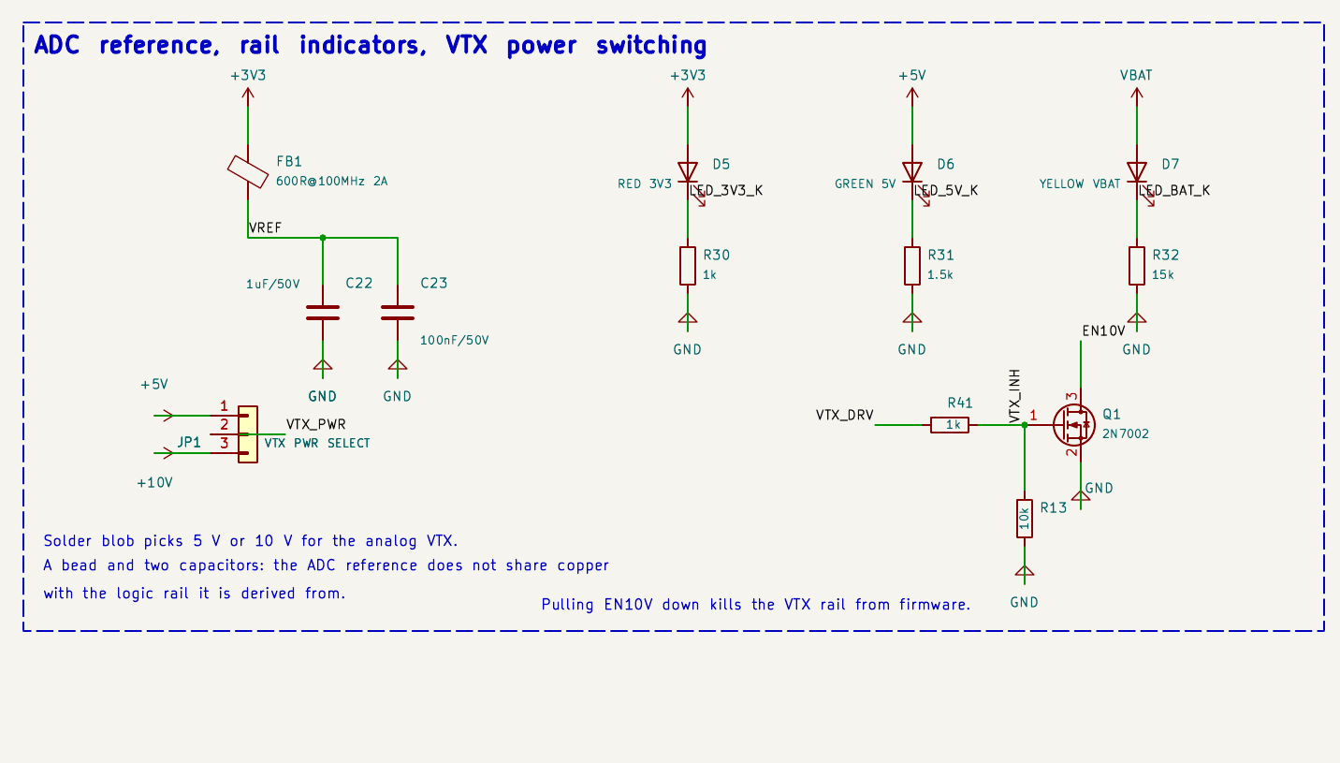
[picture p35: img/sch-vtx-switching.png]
ADC reference, rail indicators and the VTX power switch


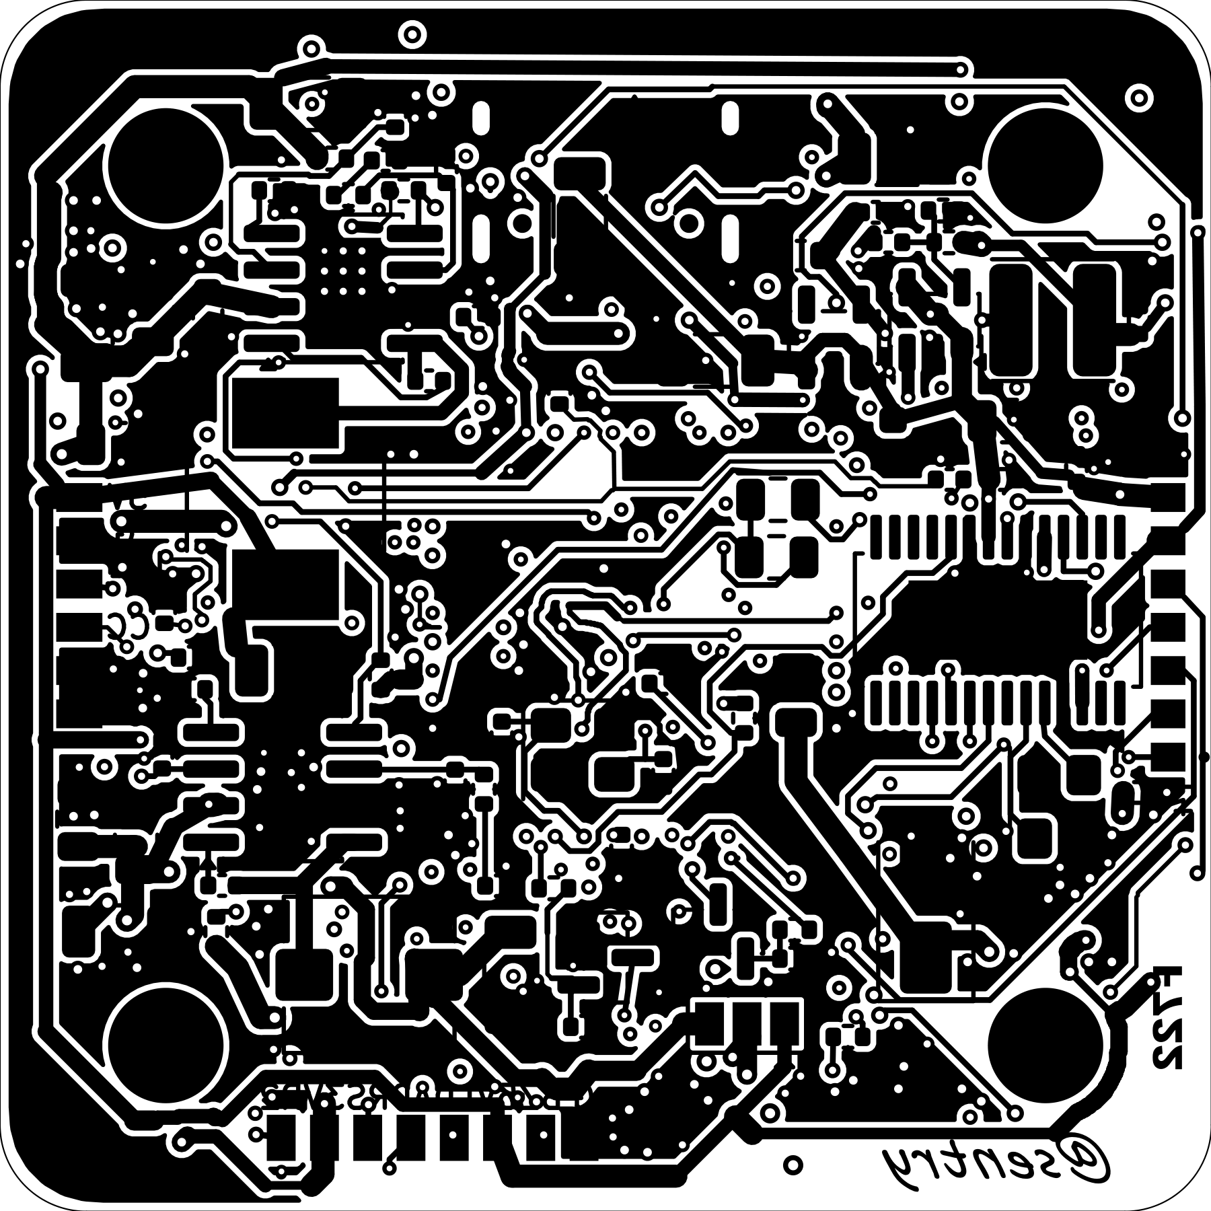
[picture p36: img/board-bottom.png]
bottom side


**Total time spent: 3.7 hours**

# September 22: R5, R6, and the production files

Last two revisions, then the files that actually go to the fab.

**R5: the silkscreen was lying.** Seven of ten connectors mislabelled. J10 pad 2
said M5 and it is ground. Pad 3 said M6 and it is camera control - both left over
from when this was a six-motor board. J11's buzzer pad had no label at all and
BZ- sat over the ground pad next to it. J1's legend was drawn at 1.5 mm pitch
over 1.0 mm pads, so CUR sat over the telemetry pin. Somebody soldering an LED
strip to the pad marked M5 would have shorted it to ground, and **none of that
shows up in DRC or ERC** - the copper is correct, the writing on top of it is
not. All 41 stale labels deleted, 42 new ones placed, one per pad.

Also bumped the ADC series resistors from 1k to 2.2k. PC0-PC3 are not 5 V
tolerant, and at 1k a 12 V miswire injects 8 mA into the clamp against a 5 mA
limit.

**R6: zero means zero.** Chased the last four ERC warnings instead of calling
them benign, which after the junction dots I no longer trust myself to do. One
was the gyro's FSYNC pin typed wrong in my own symbol. Three were labels sitting
on top of wire crossings. **ERC: 0 errors, 0 warnings.** Got five more vias out
of reflowed pads, twelve down to seven; the remaining seven are boxed in by their
own escape routing and moving them means rerouting nets that currently work.
DRC is 0 errors and one silkscreen warning I am deliberately leaving - a legend
character clipping the OSD's outline, cosmetic, and chasing it broke the
footprint link last time I tried.

**Then the production files.** BOM and CPL generated from the board itself rather
than the schematic, so what gets ordered is what is actually placed:

- **69 distinct lines, 137 placements** - 66 on top, 71 on the bottom
- Every line carries an **LCSC part number**, so the whole board assembles from
  JLCPCB stock with nothing for me to supply
- Parts on both sides, so it is **Standard PCBA**, 70 x 70 mm minimum panel,
  42 x 42 board, ordered as a 2 x 2
- Netlist cross-checked both directions: **483 pins, 105 nets, schematic and
  board agree**

Wrote the README and the pinout document last. The pinout one matters more than
it sounds: the silkscreen only has room for one or two characters beside a 1 mm
pad pitch, so `B G C R 1 2 3 4` on the ESC header needs a legend somewhere, and
the firmware notes - the DShot burst-mode flag, the timer and DMA table, which
UART is which - belong next to it rather than in my head.

Six revisions to get one board right. Looking at the finished copper, the routes
zig-zag everywhere: 45-degree dog-legs weaving round the escape ring, doubling
back to find a gap. Looks exactly like the roads back home. Nothing goes
straight, everything gets there.

R1 was 5.5 out of 10 and I thought it was nearly done. R6 has 0 DRC errors, 0 ERC
errors, 483 pads matching the schematic pin for pin, and every conductor inside
its rating. The distance between those two boards is this entire journal.

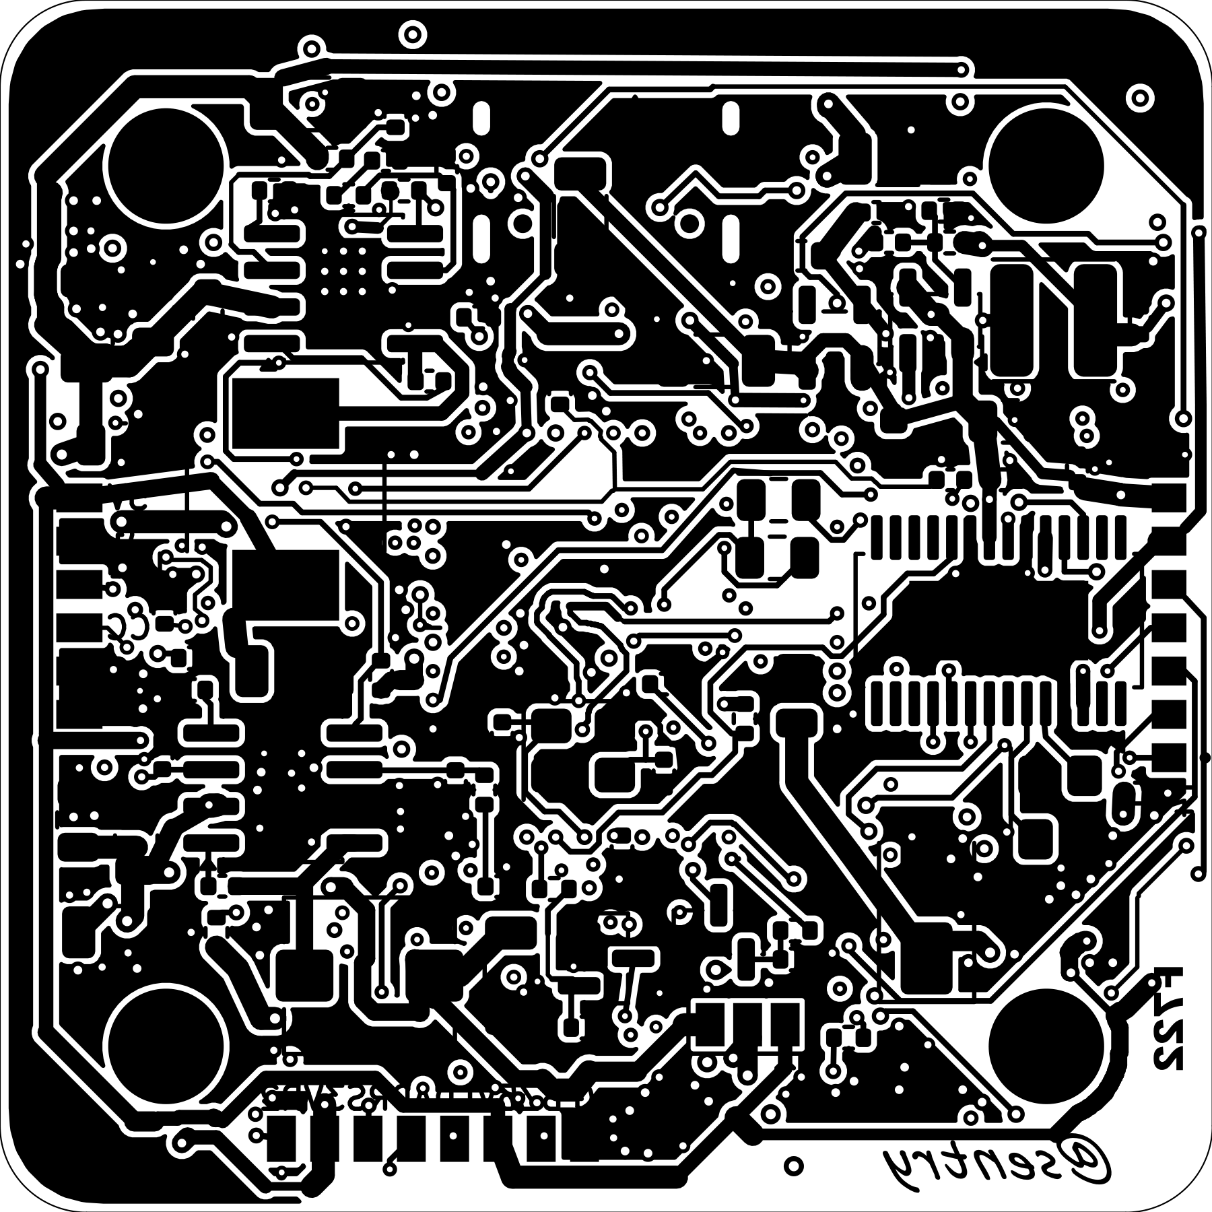
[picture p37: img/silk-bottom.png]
bottom silkscreen


the board this turned into

## Production renders

The final production views show both assembly states and both sides of the
board. The no-component views are useful for checking the bare PCB and the
component views make the placement and connector orientation easy to inspect.

front, no components

back, no components

front, components fitted

back, components fitted

**Total time spent: 3.4 hours**

# September 22: Final Submission, Cart, Total

So depending on the grant I have two options:
## 1. Buy from JLCPCB.com 

So basically its about 330USD + 11USD shipping that's about 345USD... and then remaining amount I might need for customs depending on shipping to IND or AUS...

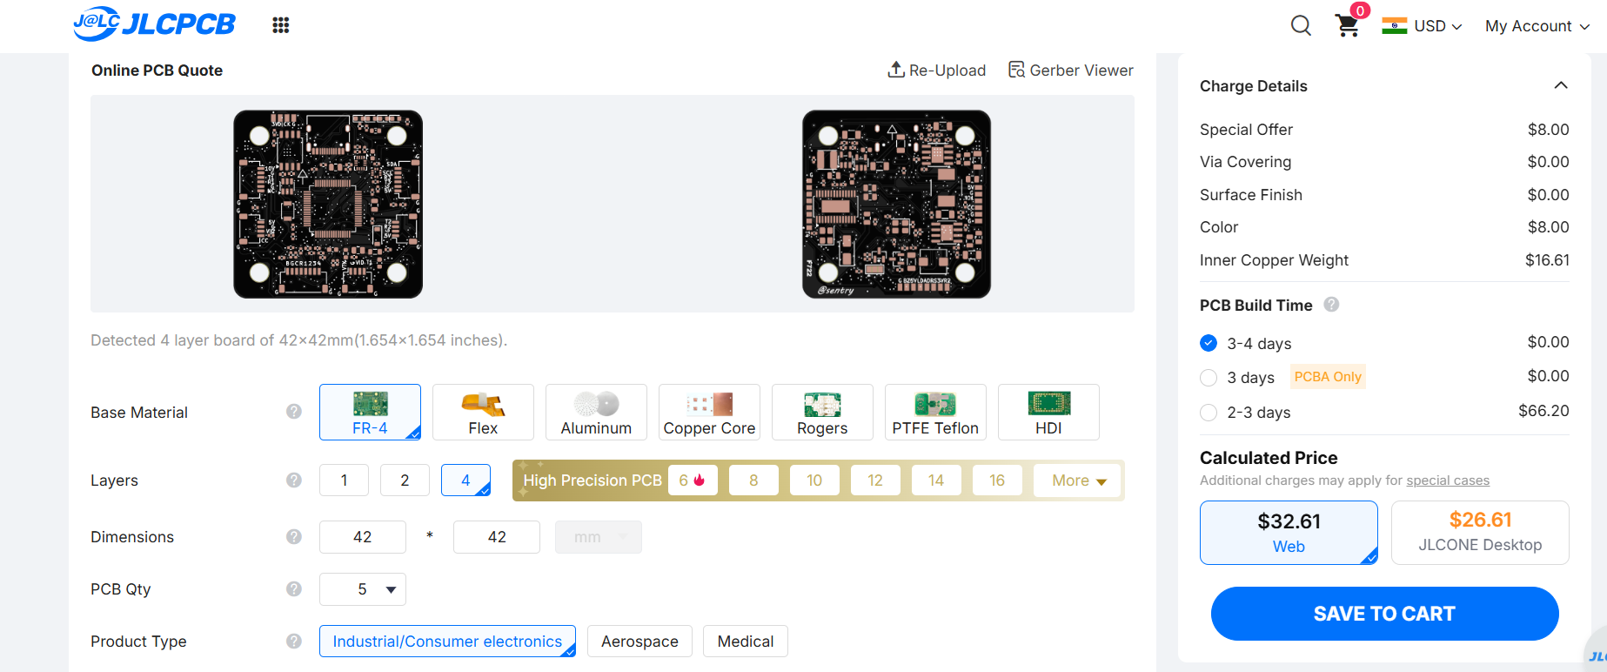
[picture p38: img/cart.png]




## 2. Local Source

If HackClub or Forge or HCB does decline using PCBA from JLCPCB, then I might need to buy some hardware for soldering BGA, 0401, LQ64 packages. And if so, I would be using Robu.in, Amazon.in, Zboitic.com, For PCB, components, Hardware stuff like Hot Plate, Tweezers, Solder Paste, Solder Flux.

Happy Clubbing !!!
Thanks, I hope you like my Project ^.^ 

**Total time spent: 0.1 hours**

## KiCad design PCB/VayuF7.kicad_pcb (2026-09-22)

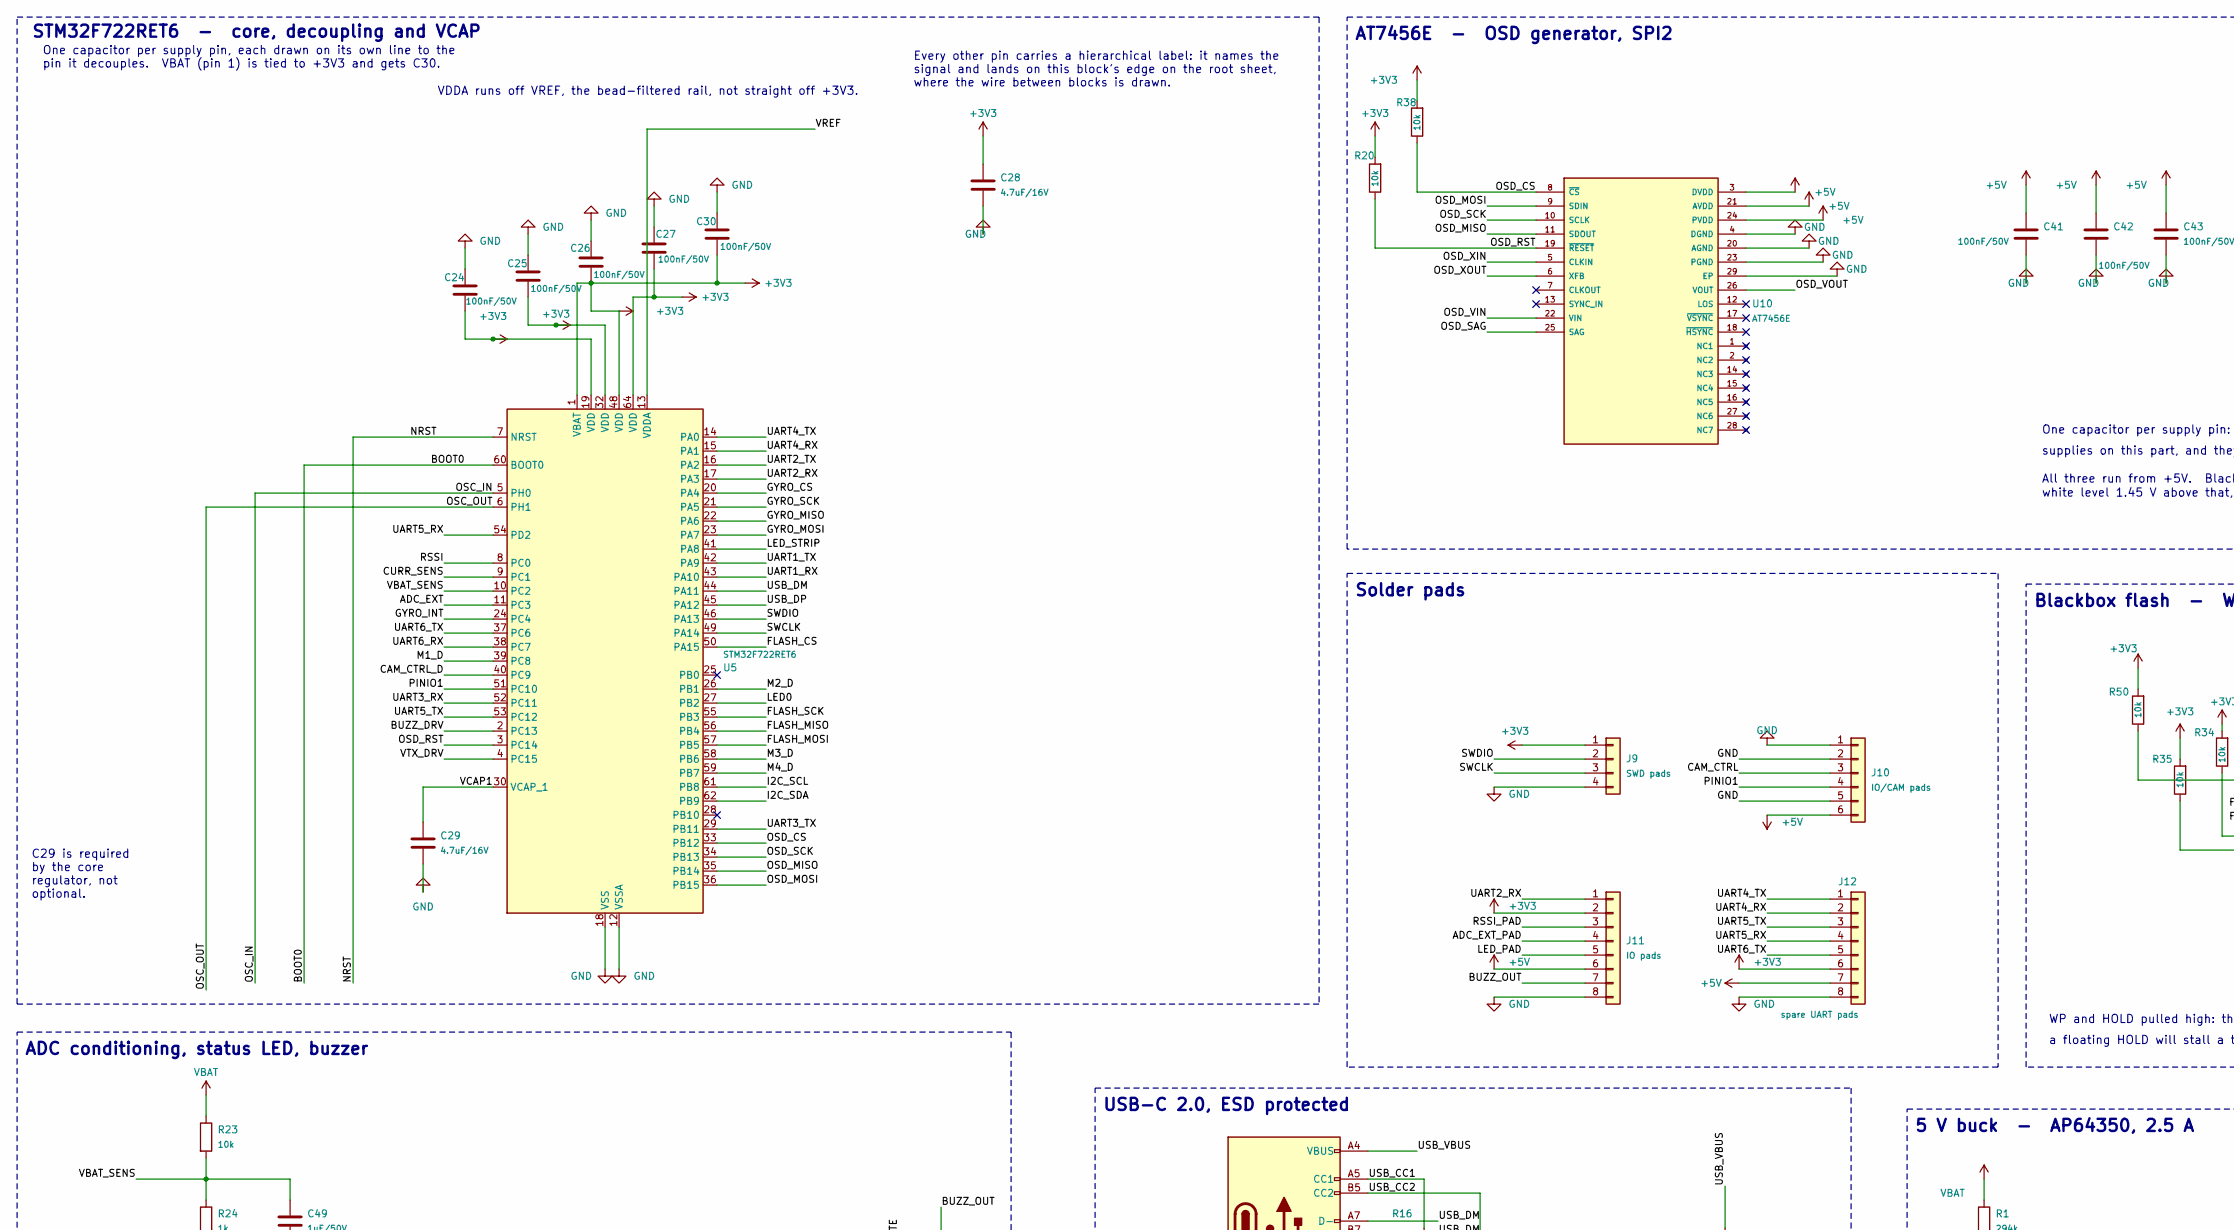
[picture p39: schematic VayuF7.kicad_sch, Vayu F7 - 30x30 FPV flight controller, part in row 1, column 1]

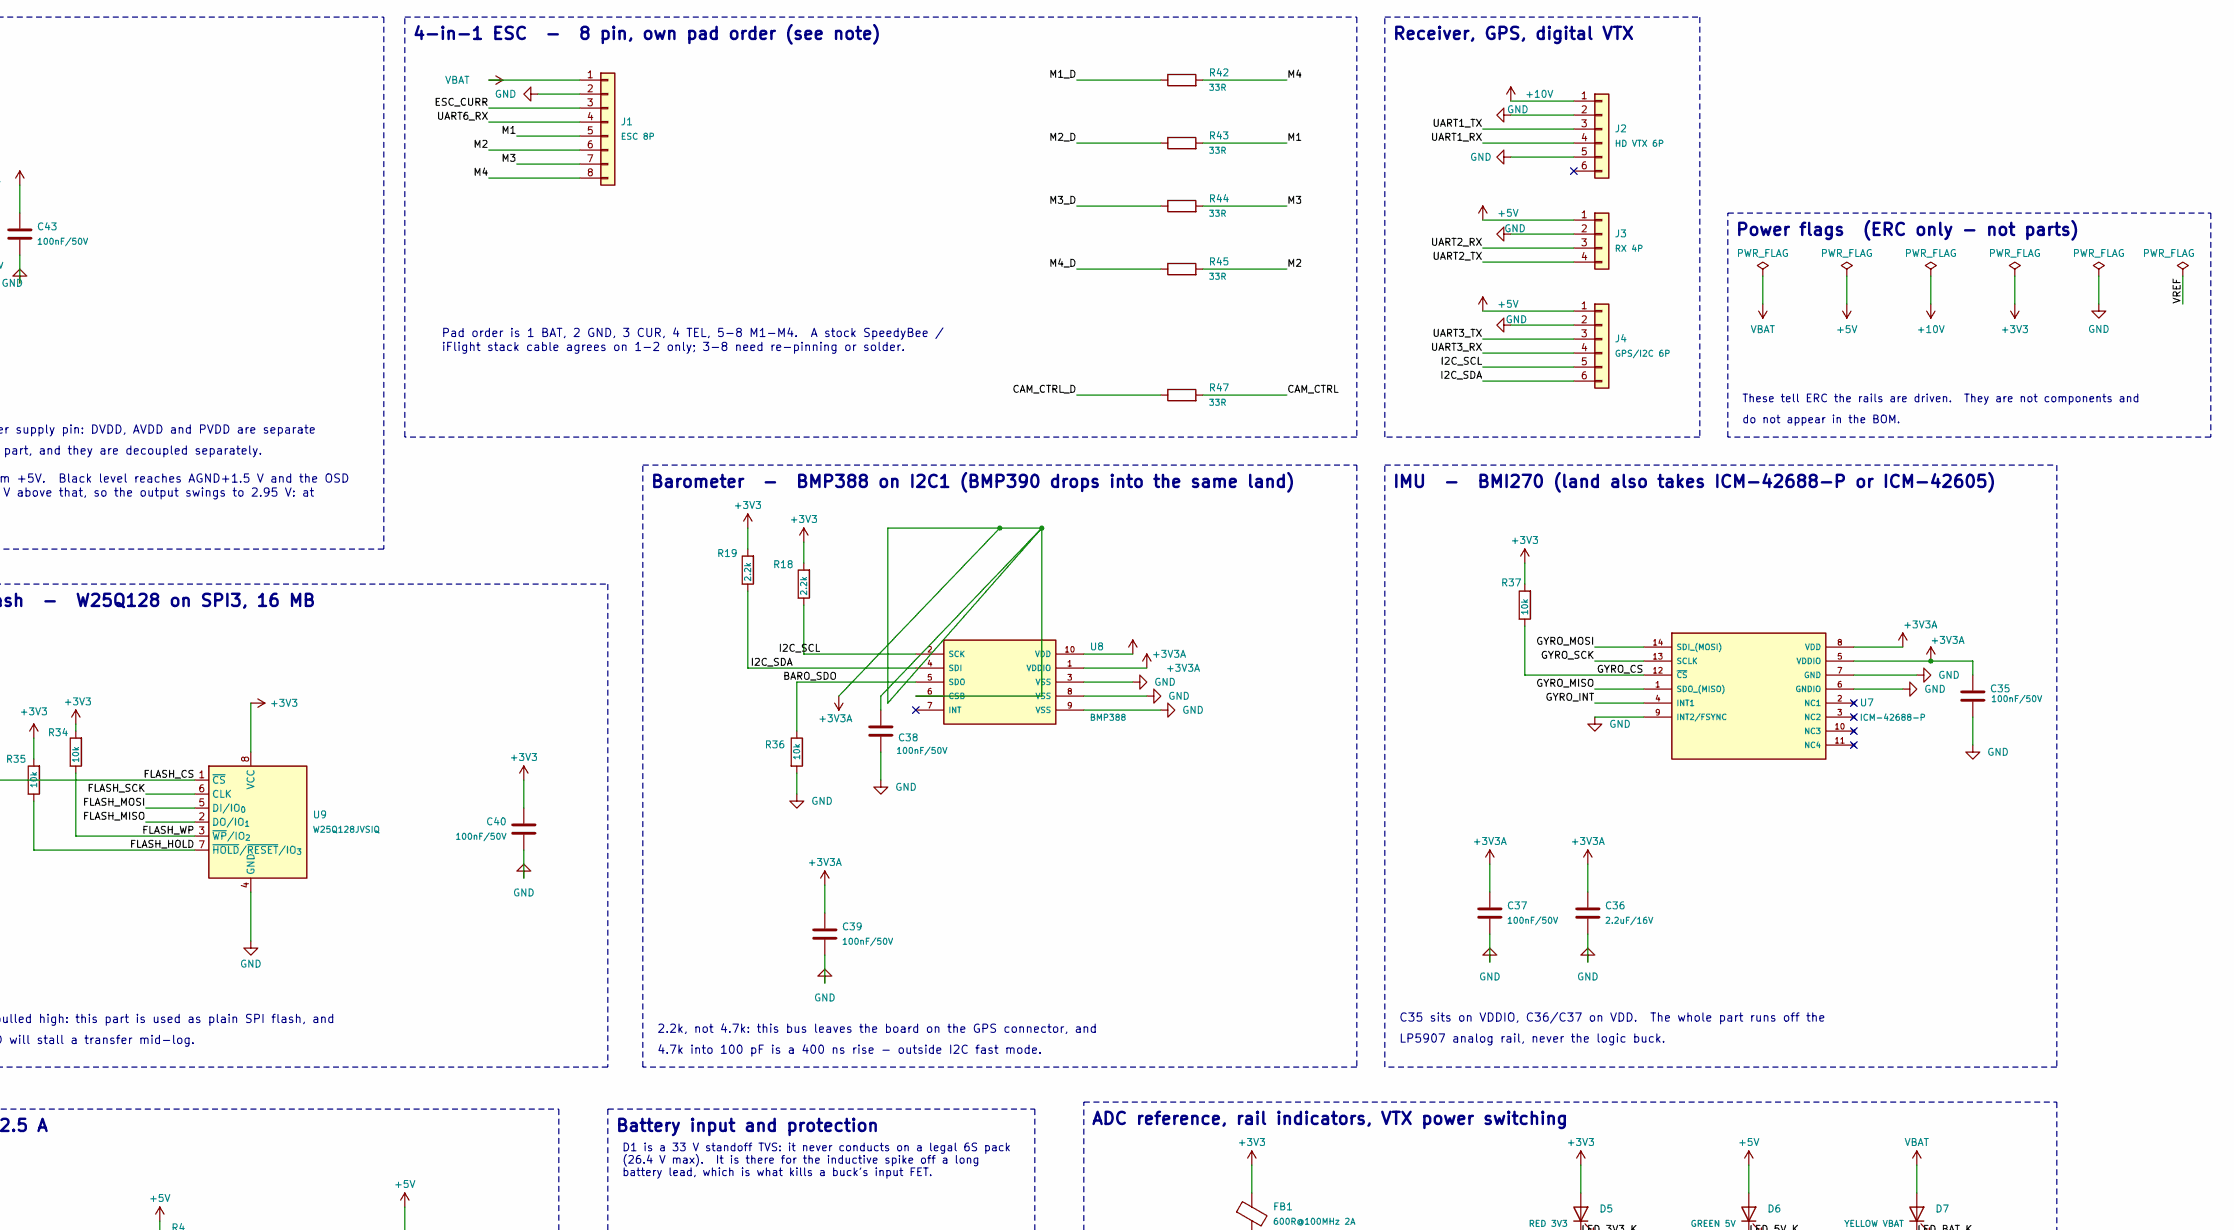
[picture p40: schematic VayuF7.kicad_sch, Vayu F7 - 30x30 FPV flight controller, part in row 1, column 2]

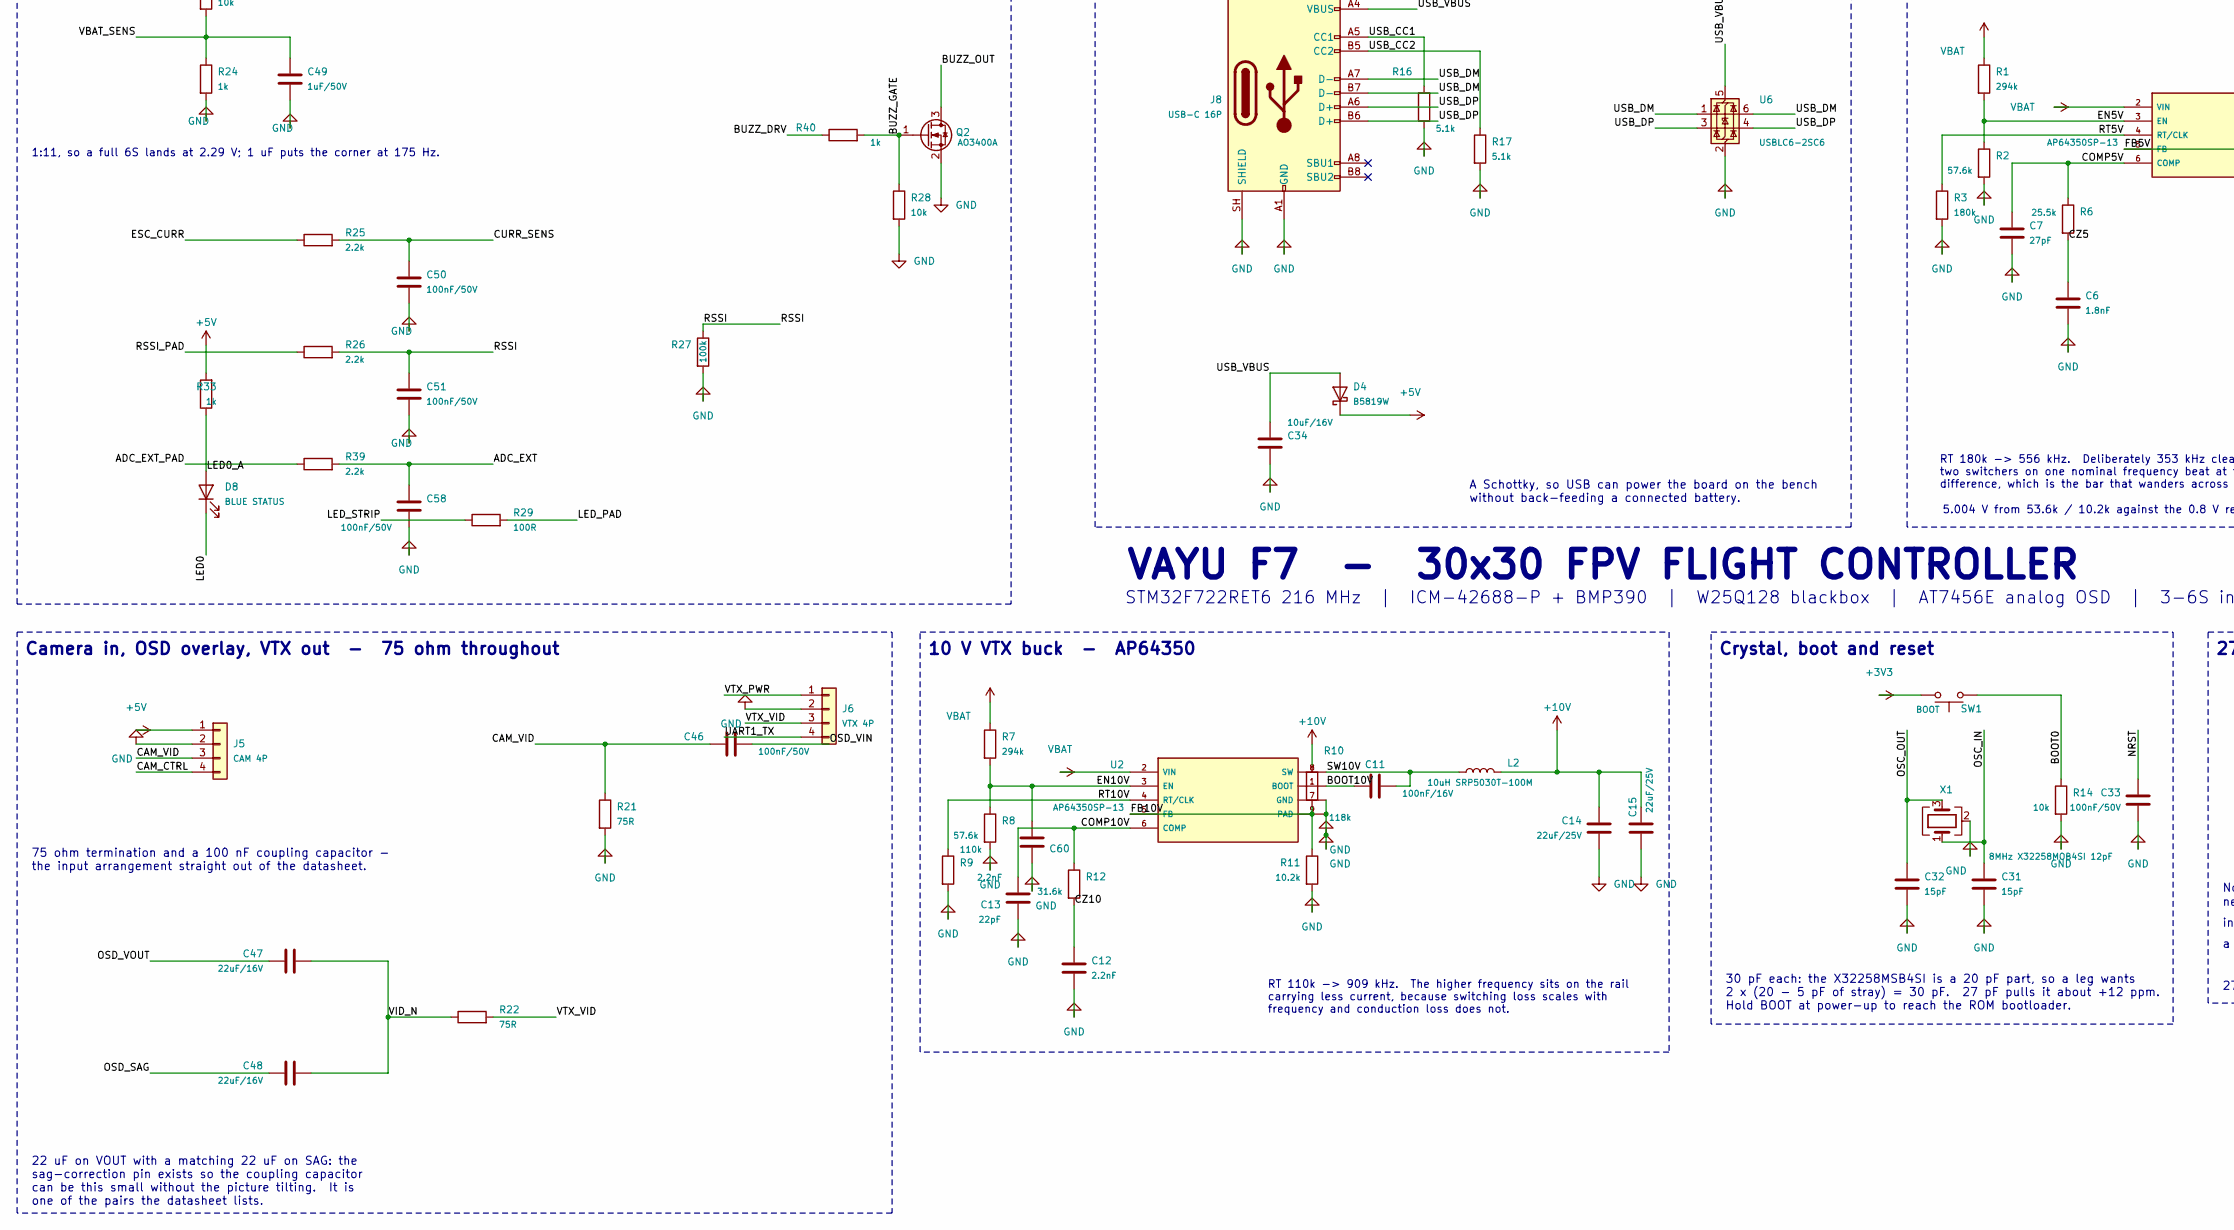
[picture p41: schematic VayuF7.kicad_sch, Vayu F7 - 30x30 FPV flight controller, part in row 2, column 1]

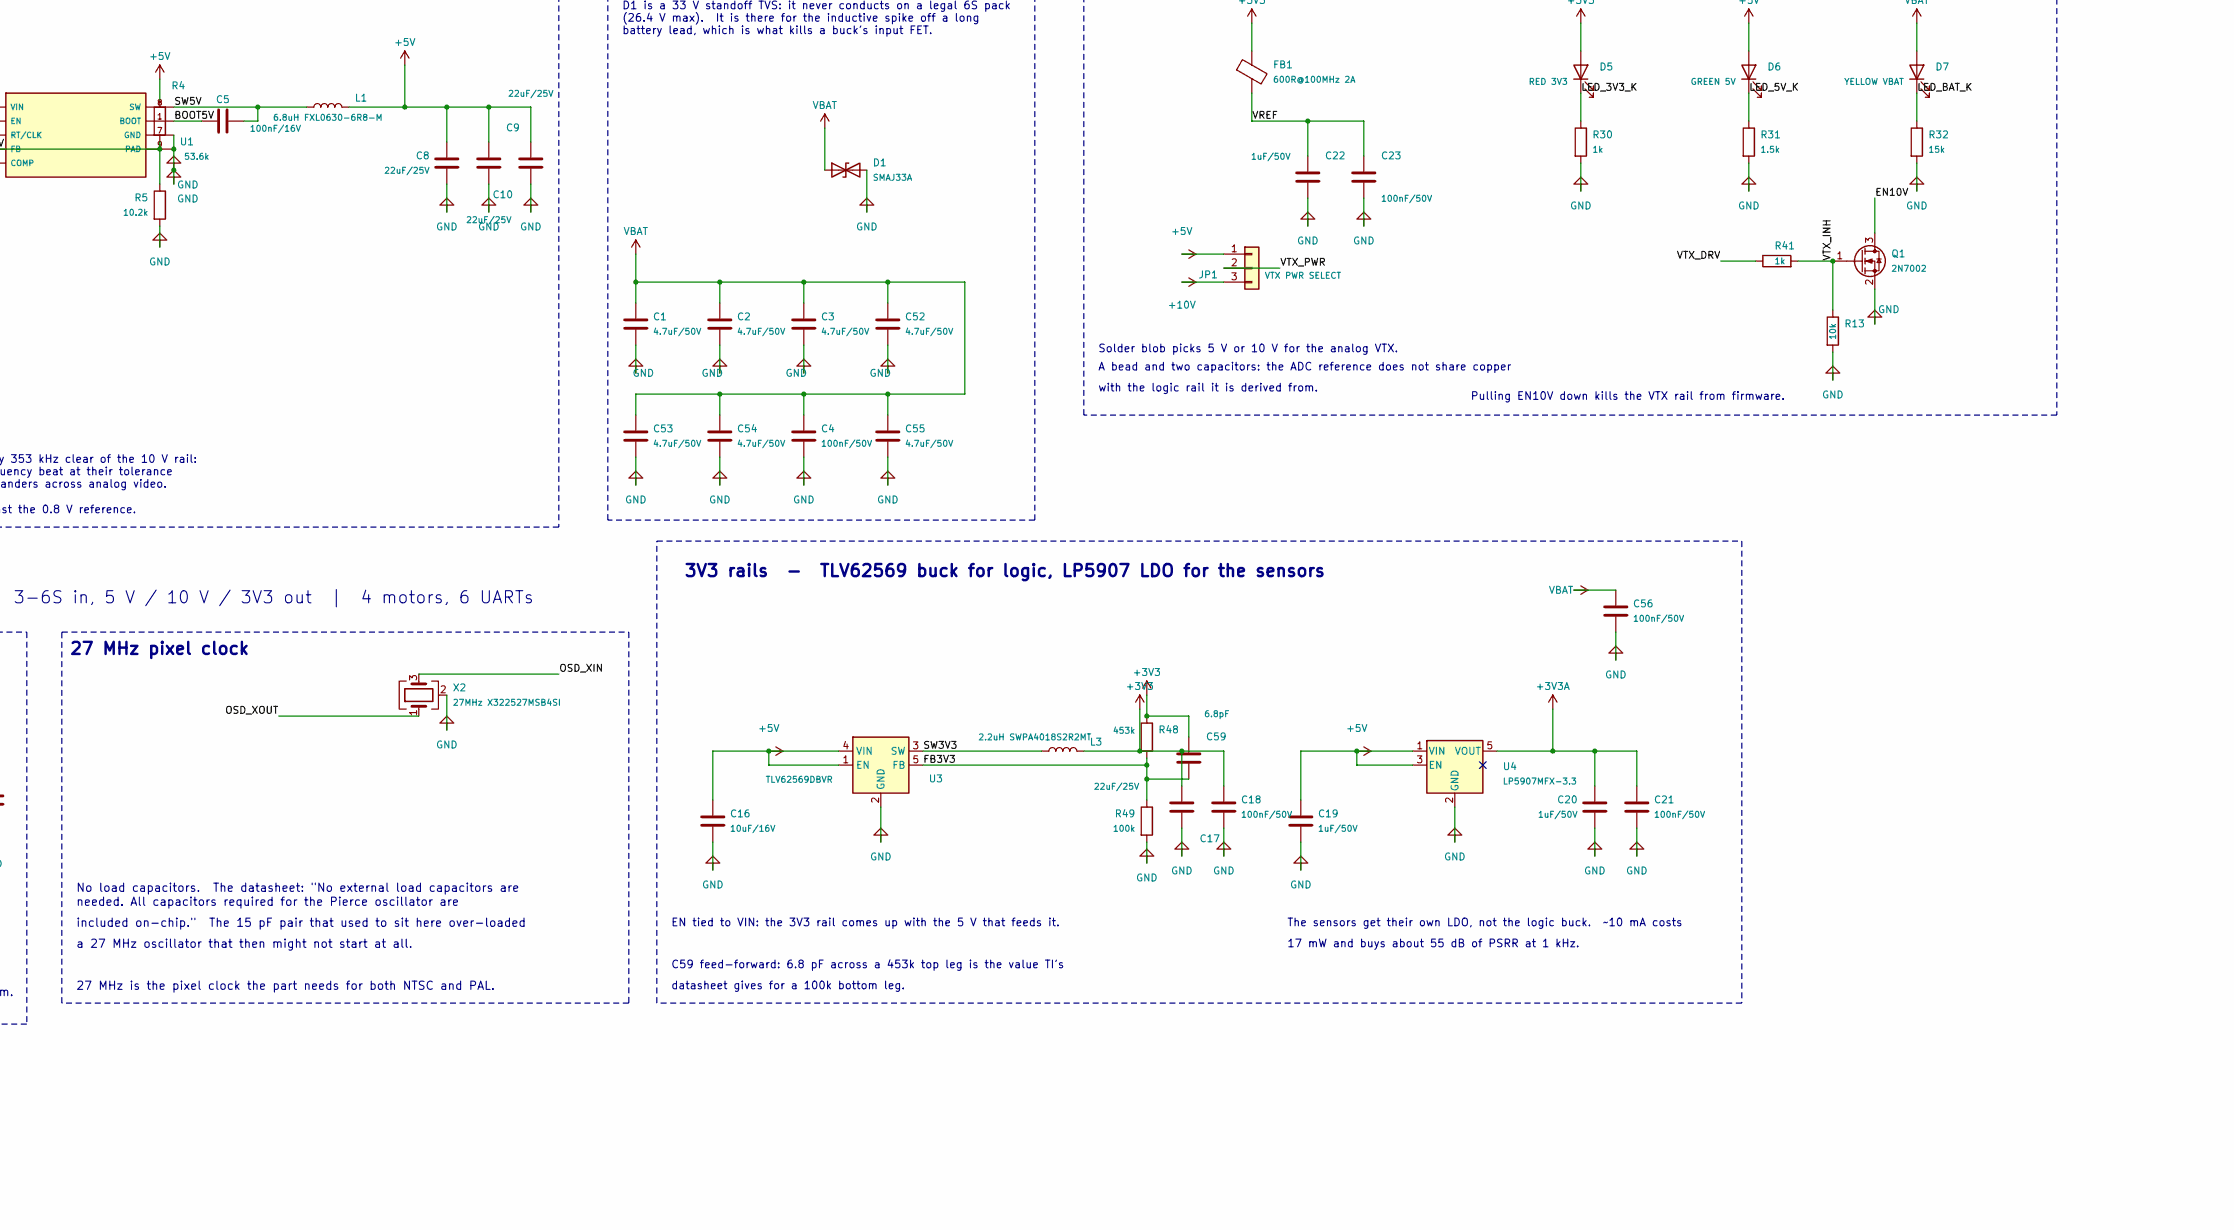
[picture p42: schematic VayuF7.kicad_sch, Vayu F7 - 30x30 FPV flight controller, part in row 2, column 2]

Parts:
C1, C2: 4.7uF/50V; C_1206_3216Metric; LCSC C29823
C3, C52, C53, C54, C55: 4.7uF/50V; C_0805_2012Metric; LCSC C437557
C4: 100nF/50V; C_0603_1608Metric; LCSC C14663
C5, C11: 100nF/16V; C_0402_1005Metric; LCSC C1525
C6: 1.8nF; C_0402_1005Metric; LCSC C107024
C7: 27pF; C_0402_1005Metric; LCSC C107002
C8, C9, C10, C14, C15, C17: 22uF/25V; C_1206_3216Metric; LCSC C12891
C12, C60: 2.2nF; C_0402_1005Metric; LCSC C1531
C13: 22pF; C_0402_1005Metric; LCSC C106203
C16, C34: 10uF/16V; C_0805_2012Metric; LCSC C3039694
C18, C21, C23, C24, C25, C26, C27, C30, C33, C35, C37, C38, C39, C40, C41, C42, C43, C46, C50, C51, C56, C58: 100nF/50V; C_0402_1005Metric; LCSC C307331
C19, C20, C22, C49: 1uF/50V; C_0603_1608Metric; LCSC C5199872
C28, C29: 4.7uF/16V; C_0805_2012Metric; LCSC C2885646
C31, C32: 15pF; C_0402_1005Metric; LCSC C107004
C36: 2.2uF/16V; C_0603_1608Metric; LCSC C415535
C47, C48: 22uF/16V; C_0805_2012Metric; LCSC C45783
C59: 6.8pF; C_0402_1005Metric; LCSC C189470
D1: SMAJ33A; D_SMA; LCSC C908777
D4: B5819W; D_SOD-123; LCSC C64885
D5: RED 3V3; LED_0603_1608Metric; LCSC C2286
D6: GREEN 5V; LED_0603_1608Metric; LCSC C965804
D7: YELLOW VBAT; LED_0603_1608Metric; LCSC C965802
D8: BLUE STATUS; LED_0603_1608Metric; LCSC C965807
FB1: 600R@100MHz 2A; L_0805_2012Metric; LCSC C1017
J1: ESC 8P; JST_SH_SM08B-SRSS-TB_1x08-1MP_P1.00mm_Horizontal; LCSC C160407
J2: HD VTX 6P; JST_SH_SM06B-SRSS-TB_1x06-1MP_P1.00mm_Horizontal; LCSC C53055322
J3: RX 4P; JST_SH_SM04B-SRSS-TB_1x04-1MP_P1.00mm_Horizontal; LCSC C160404
J4: GPS/I2C 6P; JST_SH_SM06B-SRSS-TB_1x06-1MP_P1.00mm_Horizontal; LCSC C53055322
J5: CAM 4P; JST_SH_SM04B-SRSS-TB_1x04-1MP_P1.00mm_Horizontal; LCSC C160404
J6: VTX 4P; JST_SH_SM04B-SRSS-TB_1x04-1MP_P1.00mm_Horizontal; LCSC C160404
J8: USB-C 16P; USB_C_Receptacle_HRO_TYPE-C-31-M-12; LCSC C165948
J9: SWD pads; SolderPad_1x04_P1.50mm_1.0x1.6mm
J10: IO/CAM pads; SolderPad_1x06_P1.50mm_1.0x1.6mm
J11: IO pads; SolderPad_1x08_P1.50mm_1.0x1.6mm
J12: spare UART pads; SolderPad_1x08_P1.50mm_1.0x1.2mm
JP1: VTX PWR SELECT; SolderJumper-3_P1.3mm_Open_Pad1.0x1.5mm
L1: 6.8uH FXL0630-6R8-M; L_cjiang_FXL0630; LCSC C167221
L2: 10uH SRP5030T-100M; L_Bourns_SRP5030T; LCSC C189932
L3: 2.2uH SWPA4018S2R2MT; L_Sunlord_SWPA4018S; LCSC C50543
Q1: 2N7002; SOT-23; LCSC C8545
Q2: AO3400A; SOT-23; LCSC C20917
R1, R7: 294k; R_0402_1005Metric; LCSC C159047
R2, R8: 57.6k; R_0402_1005Metric; LCSC C2960799
R3: 180k; R_0402_1005Metric; LCSC C2909325
R4: 53.6k; R_0402_1005Metric; LCSC C53398
R5, R11: 10.2k; R_0402_1005Metric; LCSC C5153958
R6: 25.5k; R_0402_1005Metric; LCSC C2998160
R9: 110k; R_0402_1005Metric; LCSC C2909311
R10: 118k; R_0402_1005Metric; LCSC C25748
R12: 31.6k; R_0402_1005Metric; LCSC C2998091
R13, R14, R20, R28, R34, R35, R36, R37, R38, R50: 10k; R_0402_1005Metric; LCSC C25744
R16, R17: 5.1k; R_0402_1005Metric; LCSC C25905
R18, R19, R25, R26, R39: 2.2k; R_0402_1005Metric; LCSC C25879
R21, R22: 75R; R_0402_1005Metric; LCSC C2909384
R23: 10k; R_0603_1608Metric; LCSC C25804
R24, R30, R33, R40, R41: 1k; R_0402_1005Metric; LCSC C11702
R27, R49: 100k; R_0402_1005Metric; LCSC C25741
R29: 100R; R_0402_1005Metric; LCSC C22369194
R31: 1.5k; R_0402_1005Metric; LCSC C25867
R32: 15k; R_0603_1608Metric; LCSC C22809
R42, R43, R44, R45, R47: 33R; R_0402_1005Metric; LCSC C2906868
R48: 453k; R_0402_1005Metric; LCSC C3013172
SW1: BOOT; SW_SPST_B3U-1000P; LCSC C231329
U1, U2: AP64350SP-13; SOIC-8-1EP_3.9x4.9mm_P1.27mm_EP2.62x3.51mm; LCSC C2071691
U3: TLV62569DBVR; SOT-23-5; LCSC C141836
U4: LP5907MFX-3.3; SOT-23-5; LCSC C80670
U5: STM32F722RET6; LQFP-64_10x10mm_P0.5mm; LCSC C118207
U6: USBLC6-2SC6; SOT-23-6; LCSC C2687116
U7: ICM-42688-P; Bosch_LGA-14_3x2.5mm_P0.5mm; LCSC C1850418
U8: BMP388; Bosch_LGA-10_2x2mm_BMP388_BMP390; LCSC C779278
U9: W25Q128JVSIQ; SOIC-8_5.3x5.3mm_P1.27mm; LCSC C97521
U10: AT7456E; HTSSOP-28-1EP_4.4x9.7mm_P0.65mm_EP2.75x6.2mm; LCSC C82351
X1: 8MHz X32258MOB4SI 12pF; Crystal_SMD_3225-4Pin_3.2x2.5mm; LCSC C2682775
X2: 27MHz X322527MSB4SI; Crystal_SMD_3225-4Pin_3.2x2.5mm; LCSC C9008

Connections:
+3V3A: C20.1, C21.1, C35.1, C36.1, C37.1, C38.1, C39.1, U4.5 (VOUT), U7.5 (VDDIO), U7.8 (VDD), U8.1 (VDDIO), U8.6 (CSB), U8.10 (VDD)
ADC_EXT: C58.1, R39.2, U5.11 (PC3)
ADC_EXT_PAD: J11.4, R39.1
BARO_SDO: R36.1, U8.5 (SDO)
BOOT0: R14.1, SW1.1, U5.60 (BOOT0)
BOOT5V: C5.1, U1.1 (BOOT)
BOOT10V: C11.1, U2.1 (BOOT)
BUZZ_DRV: R40.1, U5.2 (PC13)
BUZZ_GATE: Q2.1 (G), R28.1, R40.2
BUZZ_OUT: J11.7, Q2.3 (D)
CAM_CTRL: J5.4, J10.3, R47.2
CAM_CTRL_D: R47.1, U5.40 (PC9)
CAM_VID: C46.1, J5.3, R21.1
COMP5V: C7.1, R6.1, U1.6 (COMP)
COMP10V: C13.1, R12.1, U2.6 (COMP)
CURR_SENS: C50.1, R25.2, U5.9 (PC1)
CZ5: C6.1, R6.2
CZ10: C12.1, R12.2
EN5V: R1.2, R2.1, U1.3 (EN)
EN10V: C60.1, Q1.3 (D), R7.2, R8.1, U2.3 (EN)
ESC_CURR: J1.3, R25.1
FB3V3: C59.2, R48.2, R49.1, U3.5 (FB)
FB5V: R4.2, R5.1, U1.5 (FB)
FB10V: R10.2, R11.1, U2.5 (FB)
FLASH_CS: R50.1, U5.50 (PA15), U9.1 (~CS)
FLASH_HOLD: R35.1, U9.7 (~HOLD/~RESET/IO_{3})
FLASH_MISO: U5.56 (PB4), U9.2 (DO/IO_{1})
FLASH_MOSI: U5.57 (PB5), U9.5 (DI/IO_{0})
FLASH_SCK: U5.55 (PB3), U9.6 (CLK)
FLASH_WP: R34.1, U9.3 (~WP/IO_{2})
GYRO_CS: R37.1, U5.20 (PA4), U7.12 (~CS)
GYRO_INT: U5.24 (PC4), U7.4 (INT1)
GYRO_MISO: U5.22 (PA6), U7.1 (SDO_(MISO))
GYRO_MOSI: U5.23 (PA7), U7.14 (SDI_(MOSI))
GYRO_SCK: U5.21 (PA5), U7.13 (SCLK)
I2C_SCL: J4.5, R18.1, U5.61 (PB8), U8.2 (SCK)
I2C_SDA: J4.6, R19.1, U5.62 (PB9), U8.4 (SDI)
LED0: D8.1 (K), U5.27 (PB2)
LED0_A: D8.2 (A), R33.1
LED_3V3_K: D5.1 (K), R30.1
LED_5V_K: D6.1 (K), R31.1
LED_BAT_K: D7.1 (K), R32.1
LED_PAD: J11.5, R29.2
LED_STRIP: R29.1, U5.41 (PA8)
M1: J1.5, R43.2
M1_D: R42.1, U5.39 (PC8)
M2: J1.6, R45.2
M2_D: R43.1, U5.26 (PB1)
M3: J1.7, R44.2
M3_D: R44.1, U5.58 (PB6)
M4: J1.8, R42.2
M4_D: R45.1, U5.59 (PB7)
NRST: C33.1, U5.7 (NRST)
OSC_IN: C31.1, U5.5 (PH0), X1.1
OSC_OUT: C32.1, U5.6 (PH1), X1.3
OSD_CS: R38.1, U5.33 (PB12), U10.8 (~CS)
OSD_MISO: U5.35 (PB14), U10.11 (SDOUT)
OSD_MOSI: U5.36 (PB15), U10.9 (SDIN)
OSD_RST: R20.1, U5.3 (PC14), U10.19 (~RESET)
OSD_SAG: C48.1, U10.25 (SAG)
OSD_SCK: U5.34 (PB13), U10.10 (SCLK)
OSD_VIN: C46.2, U10.22 (VIN)
OSD_VOUT: C47.1, U10.26 (VOUT)
OSD_XIN: U10.5 (CLKIN), X2.3
OSD_XOUT: U10.6 (XFB), X2.1
PINIO1: J10.4, U5.51 (PC10)
RSSI: C51.1, R26.2, R27.1, U5.8 (PC0)
RSSI_PAD: J11.3, R26.1
RT5V: R3.1, U1.4 (RT/CLK)
RT10V: R9.1, U2.4 (RT/CLK)
SW3V3: L3.1, U3.3 (SW)
SW5V: C5.2, L1.1, U1.8 (SW)
SW10V: C11.2, L2.1, U2.8 (SW)
SWCLK: J9.3, U5.49 (PA14)
SWDIO: J9.2, U5.46 (PA13)
UART1_RX: J2.4, U5.43 (PA10)
UART1_TX: J2.3, J6.4, U5.42 (PA9)
UART2_RX: J3.3, J11.1, U5.17 (PA3)
UART2_TX: J3.4, U5.16 (PA2)
UART3_RX: J4.4, U5.52 (PC11)
UART3_TX: J4.3, U5.29 (PB11)
UART4_RX: J12.2, U5.15 (PA1)
UART4_TX: J12.1, U5.14 (PA0)
UART5_RX: J12.4, U5.54 (PD2)
UART5_TX: J12.3, U5.53 (PC12)
UART6_RX: J1.4, U5.38 (PC7)
UART6_TX: J12.5, U5.37 (PC6)
USB_CC1: J8.A5 (CC1), R16.1
USB_CC2: J8.B5 (CC2), R17.1
USB_DM: J8.A7 (D-), J8.B7 (D-), U5.44 (PA11), U6.1 (I/O1), U6.6 (I/O1)
USB_DP: J8.A6 (D+), J8.B6 (D+), U5.45 (PA12), U6.3 (I/O2), U6.4 (I/O2)
USB_VBUS: C34.1, D4.2 (A), J8.A4 (VBUS), J8.A9 (VBUS), J8.B4 (VBUS), J8.B9 (VBUS), U6.5 (VBUS)
VBAT_SENS: C49.1, R23.2, R24.1, U5.10 (PC2)
VCAP1: C29.1, U5.30 (VCAP_1)
VID_N: C47.2, C48.2, R22.1
VTX_DRV: R41.1, U5.4 (PC15)
VTX_INH: Q1.1 (G), R13.1, R41.2
VTX_PWR: J6.1, JP1.2
VTX_VID: J6.3, R22.2

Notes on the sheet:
10 V VTX buck - AP64350
iFlight stack cable agrees on 1-2 only; 3-8 need re-pinning or solder.
4-in-1 ESC - 8 pin, own pad order (see note)
All three run from +5V. Black level reaches AGND+1.5 V and the OSD
One capacitor per supply pin, each drawn on its own line to the pin it decouples. VBAT (pin 1) is tied to +3V3 and gets C30.
C59 feed-forward: 6.8 pF across a 453k top leg is the value TI's
supplies on this part, and they are decoupled separately.
datasheet gives for a 100k bottom leg.
17 mW and buys about 55 dB of PSRR at 1 kHz.
a 27 MHz oscillator that then might not start at all.
EN tied to VIN: the 3V3 rail comes up with the 5 V that feeds it.
27 MHz is the pixel clock the part needs for both NTSC and PAL.
ADC conditioning, status LED, buzzer
5.004 V from 53.6k / 10.2k against the 0.8 V reference.
Crystal, boot and reset
Barometer - BMP388 on I2C1 (BMP390 drops into the same land)
C29 is required by the core regulator, not optional.
Battery input and protection
IMU - BMI270 (land also takes ICM-42688-P or ICM-42605)
Solder pads
LP5907 analog rail, never the logic buck.
with the logic rail it is derived from.
Receiver, GPS, digital VTX
Every other pin carries a hierarchical label: it names the signal and lands on this block's edge on the root sheet, where the wire between blocks is drawn.
D1 is a 33 V standoff TVS: it never conducts on a legal 6S pack (26.4 V max). It is there for the inductive spike off a long battery lead, which is what kills a buck's input FET.
RT 180k -> 556 kHz. Deliberately 353 kHz clear of the 10 V rail: two switchers on one nominal frequency beat at their tolerance difference, which is the bar that wanders across analog video.
STM32F722RET6 216 MHz | ICM-42688-P + BMP390 | W25Q128 blackbox | AT7456E analog OSD | 3-6S in, 5 V / 10 V / 3V3 out | 4 motors, 6 UARTs
1:11, so a full 6S lands at 2.29 V; 1 uF puts the corner at 175 Hz.
STM32F722RET6 - core, decoupling and VCAP
Camera in, OSD overlay, VTX out - 75 ohm throughout
22 uF on VOUT with a matching 22 uF on SAG: the sag-correction pin exists so the coupling capacitor can be this small without the picture tilting. It is one of the pairs the datasheet lists.
Pulling EN10V down kills the VTX rail from firmware.
WP and HOLD pulled high: this part is used as plain SPI flash, and
30 pF each: the X32258MSB4SI is a 20 pF part, so a leg wants 2 x (20 - 5 pF of stray) = 30 pF. 27 pF pulls it about +12 ppm. Hold BOOT at power-up to reach the ROM bootloader.
do not appear in the BOM.
white level 1.45 V above that, so the output swings to 2.95 V: at
No load capacitors. The datasheet: "No external load capacitors are
VAYU F7 - 30x30 FPV FLIGHT CONTROLLER
27 MHz pixel clock
Power flags (ERC only - not parts)

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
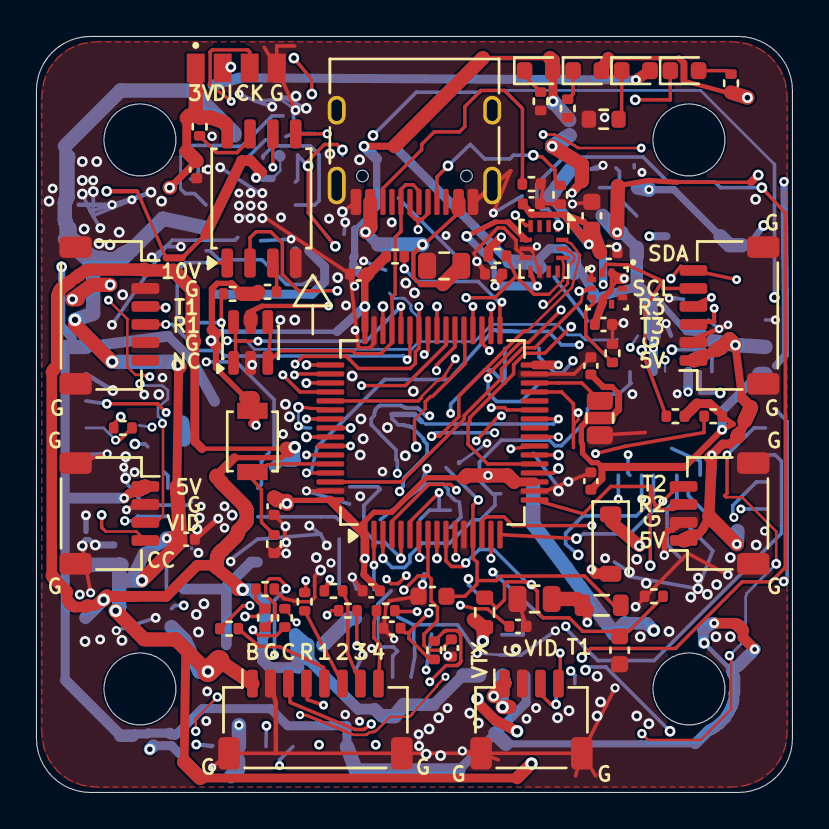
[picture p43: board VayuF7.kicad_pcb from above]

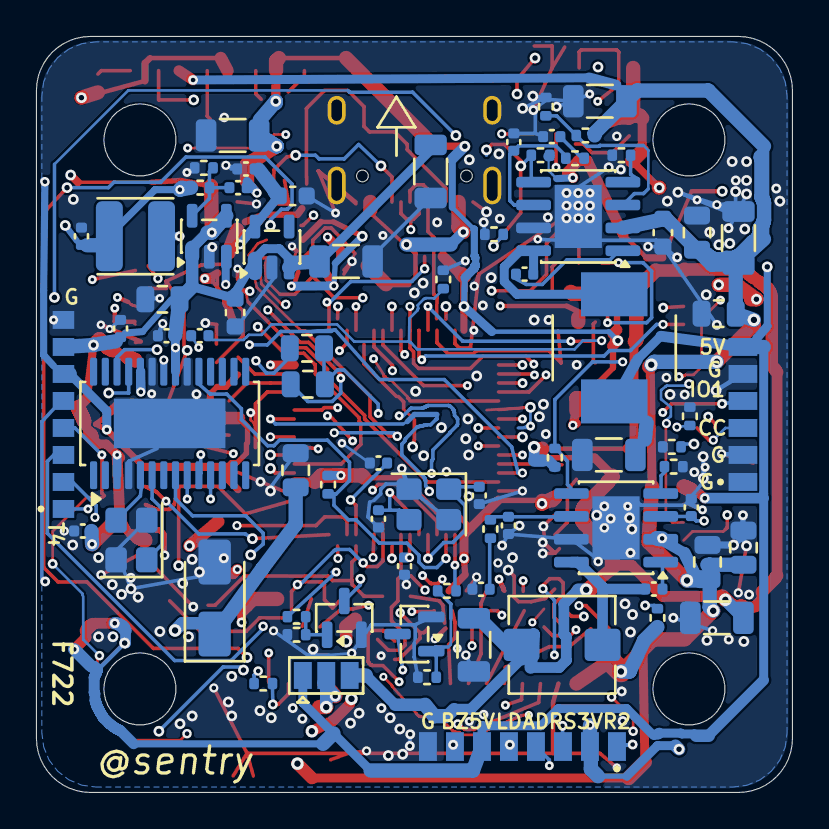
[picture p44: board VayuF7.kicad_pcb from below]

Board: 4 copper layers, 42.0 x 42.0 mm, 146 parts (75 on the bottom side), 105 nets.

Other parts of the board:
MH1, MH2, MH3, MH4: MountingHole_4mm

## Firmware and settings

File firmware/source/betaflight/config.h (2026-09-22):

#pragma once

#define TARGET_NAME "VAYUF7"
#define USE_TARGET_VAYUF7

#define MCU_STM32F722
#define TARGET_BOARD_IDENTIFIER "VAYUF7"

#define USE_ACC
#define USE_GYRO
#define USE_BARO
#define USE_FLASH
#define USE_OSD
#define USE_MAG
#define USE_RANGEFINDER

#define USE_ACC_SPI_ICM42688P
#define USE_GYRO_SPI_ICM42688P
#define USE_BARO_BMP388
#define USE_FLASH_W25Q128
#define USE_OSD_AT7456E

#define USE_UART1
#define USE_UART2
#define USE_UART3
#define USE_UART4
#define USE_UART5
#define USE_UART6

#define USE_SPI1
#define USE_SPI2
#define USE_SPI3
#define USE_I2C1

#define TARGET_RX_SPI_NONE

/* STM32F722RET6 pin mapping for the Vayu F7 board */
#define LED0_PIN PINC13
#define BEEPER_PIN PINB12
#define BIND_BUTTON_PIN PINB2
#define SDCARD_DETECT_PIN NONE

/* SPI1: ICM-42688-P */
#define SPI1_SCK_PIN PINA5
#define SPI1_MISO_PIN PINA6
#define SPI1_MOSI_PIN PINA7
#define SPI1_NSS_PIN PINA4

/* SPI2: AT7456E OSD */
#define SPI2_SCK_PIN PINB13
#define SPI2_MISO_PIN PINB14
#define SPI2_MOSI_PIN PINB15
#define SPI2_NSS_PIN PINB12

/* SPI3: W25Q128 blackbox flash */
#define SPI3_SCK_PIN PINB3
#define SPI3_MISO_PIN PINB4
#define SPI3_MOSI_PIN PINB5
#define SPI3_NSS_PIN PINA15

/* I2C1: BMP388 */
#define I2C1_SCL_PIN PINB8
#define I2C1_SDA_PIN PINB9

/* UART1: telemetry / RX */
#define UART1_TX_PIN PINA9
#define UART1_RX_PIN PINA10

/* UART2: GPS / serial RX */
#define UART2_TX_PIN PINA2
#define UART2_RX_PIN PINA3

/* UART3: ESC telemetry / external serial */
#define UART3_TX_PIN PINB10
#define UART3_RX_PIN PINB11

/* UART4: pads / RX / debug */
#define UART4_TX_PIN PINA0
#define UART4_RX_PIN PINA1

/* UART5: pads / additional serial */
#define UART5_TX_PIN PINC12
#define UART5_RX_PIN PIND2

/* UART6: extra serial / VTX or telemetry */
#define UART6_TX_PIN PINC6
#define UART6_RX_PIN PINC7

/* Motor outputs: timer-backed DShot-capable outputs */
#define MOTOR1_PIN PINA8
#define MOTOR2_PIN PINA9
#define MOTOR3_PIN PINA10
#define MOTOR4_PIN PINA11

#define MOTOR1_TIMER TIM1
#define MOTOR2_TIMER TIM1
#define MOTOR3_TIMER TIM1
#define MOTOR4_TIMER TIM1

#define MOTOR1_TIMER_CHNL 1
#define MOTOR2_TIMER_CHNL 2
#define MOTOR3_TIMER_CHNL 3
#define MOTOR4_TIMER_CHNL 4

#define ADC_CHANNEL_1_PIN PINA0
#define ADC_CHANNEL_2_PIN PINA1
#define ADC_CHANNEL_3_PIN PINA2
#define ADC_CHANNEL_4_PIN PINA3

#define DEFAULT_RX_TYPE RX_TYPE_SERIAL
#define SERIAL_PORT_COUNT 6

#define VTX_POWER_PIN PINB0
#define VTX_ENABLE_PIN PINB1

#define PINIO1_PIN NONE
#define PINIO2_PIN NONE

#define USE_DSHOT
#define USE_DSHOT_BITBANG

#define USE_ESC_SENSOR

#define USE_LED_STRIP
#define USE_OSD

#define USE_TINYGPS
#define USE_GPS
#define USE_GPS_PROTO_UBLOX

#define TARGET_HAS_BEEPER
#define TARGET_HAS_OSD
#define TARGET_HAS_FLASH

#define DEFAULT_FEATURES FEATURE_TX_PROF_SEL

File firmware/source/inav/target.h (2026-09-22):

#pragma once

#define TARGET_BOARD_IDENTIFIER "VAYUF7"
#define USE_TARGET_VAYUF7
#define USE_ACC
#define USE_GYRO
#define USE_BARO
#define USE_FLASH
#define USE_OSD
#define USE_MAG
#define USE_PWM_OUTPUT
#define USE_DSHOT

#define TARGET_MCU STM32F722xx

#define USE_SPI
#define USE_SPI_DEVICE_1
#define USE_SPI_DEVICE_2
#define USE_SPI_DEVICE_3
#define USE_I2C
#define USE_I2C_DEVICE_1

#define USE_UART1
#define USE_UART2
#define USE_UART3
#define USE_UART4
#define USE_UART5
#define USE_UART6

/* Sensor mapping for the Vayu F7 board */
#define ACC_SPI_INSTANCE SPI1
#define GYRO_SPI_INSTANCE SPI1
#define OSD_SPI_INSTANCE SPI2
#define FLASH_SPI_INSTANCE SPI3
#define BARO_I2C_INSTANCE I2C1

/* GPIO mapping: realistic board assignments for the Vayu F7 hardware */
#define ACC_CS_PIN GPIO_PIN_4
#define GYRO_CS_PIN GPIO_PIN_4
#define FLASH_CS_PIN GPIO_PIN_15
#define OSD_CS_PIN GPIO_PIN_12

#define SPI1_SCK_PIN GPIO_PIN_5
#define SPI1_MISO_PIN GPIO_PIN_6
#define SPI1_MOSI_PIN GPIO_PIN_7

#define SPI2_SCK_PIN GPIO_PIN_13
#define SPI2_MISO_PIN GPIO_PIN_14
#define SPI2_MOSI_PIN GPIO_PIN_15

#define SPI3_SCK_PIN GPIO_PIN_3
#define SPI3_MISO_PIN GPIO_PIN_4
#define SPI3_MOSI_PIN GPIO_PIN_5

#define I2C1_SCL_PIN GPIO_PIN_8
#define I2C1_SDA_PIN GPIO_PIN_9

#define UART1_TX_PIN GPIO_PIN_9
#define UART1_RX_PIN GPIO_PIN_10
#define UART2_TX_PIN GPIO_PIN_2
#define UART2_RX_PIN GPIO_PIN_3
#define UART3_TX_PIN GPIO_PIN_10
#define UART3_RX_PIN GPIO_PIN_11
#define UART4_TX_PIN GPIO_PIN_0
#define UART4_RX_PIN GPIO_PIN_1

#define MOTOR_OUTPUT_1 GPIO_PIN_8
#define MOTOR_OUTPUT_2 GPIO_PIN_9
#define MOTOR_OUTPUT_3 GPIO_PIN_10
#define MOTOR_OUTPUT_4 GPIO_PIN_11

void targetInit(void);
void targetConfigureMotorOutputs(void);

#ifndef __cplusplus
extern "C" {
#endif

extern void initBoardHardware(void);
extern void motorConfig;

#ifndef __cplusplus
}
#endif
